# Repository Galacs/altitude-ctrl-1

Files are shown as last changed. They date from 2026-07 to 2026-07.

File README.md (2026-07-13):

# Altitude CTRL 1

## Pin definitions

```c
#define I2C_RST_PIN PC13
#define I2C_SDA PB11
#define I2C_SCL PB10

#define STEPPER_STEP PB6
#define STEPPER_DIR PB5
#define STEPPER_EN PB7
#define STEPPER_TX PA2
#define STEPPER_RX PA3

#define CAN_TX_PIN PB9
#define CAN_RX_PIN PB8
#define CAN_STAT_PIN PB12

#define PRESS_SNS_PIN PA7

#define LMS_PIN PB4
#define BTN_PIN PA11
#define BAU_PIN PA15

#define PUMP_PIN PB15
#define RL_1_PIN PB14
#define RL_2_PIN PB13

#define SPI_SCK_PIN PA5
#define SPI_MISO_PIN PA6
#define SPI_CS_PIN PA4
```

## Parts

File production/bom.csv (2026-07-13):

Designator | Footprint | Quantity | Value | LCSC Part #
C1, C12, C4, C49, C50, C51, C52 | 0805 | 7 | 10u | C440198
C10, C5, C6, C7, C8, C9 | 0805 | 6 | 22u | C45783
C11, C13, C16, C17, C18, C19, C22, C47 | 0402 | 8 | 0u1 | C307331
C14, C15 | 0603 | 2 | 20p | C1648
C2, C20, C21, C3, C53 | 0402 | 5 | 1u | C52923
C35 | 0402 | 1 | 4u7 | C23733
C36 | 0402 | 1 | 22n | C1532
D1, D2 | D_SMA | 2 | SMAJ12A | C19077531
D10 | 0805 | 1 | YELLOW | C2296
D12, D14, D16, D18, D5, D6, D7, D8, D9 | Diode_DFN1006 | 9 | H5VU10U | C22395519
D3, D4 | 0805 | 2 | GREEN | C2297
FB1 | 0805 | 1 | 600Ω@100M | C81034
J7 | PinHeader_1x02_P2.54mm_Vertical | 1 | Conn_01x02
R1, R10, R11, R41, R9 | 0402 | 5 | 10k | C25744
R12 | 0603 | 1 | 560 | C23204
R13, R4, R5, R6, R8 | 0402 | 5 | 5k1 | C25905
R14 | 0402 | 1 | 100 | C705627
R15 | 1206 | 1 | 120 | C17909
R2, R3, R36, R7 | 0402 | 4 | 1k | C11702
SW1, SW3, SW5 | SW_SPST_TS-1088-xR020 | 3 | SW_Push | C720477
U1 | SOT-89-3 | 1 | HT753-1 | C14289
U2 | SOIC-16_3.9x9.9mm_P1.27mm | 1 | ULN2003A | C7512
U3, U4 | Texas_RPW0010A_VQFN-HR-10_2x2mm_P0.5mm | 2 | LM73100 | C3210761
U5 | SOIC-8_3.9x4.9mm_P1.27mm | 1 | MAX6675 | C16030
U6 | LQFP-48_7x7mm_P0.5mm | 1 | STM32F103C8Tx | C8734
U7 | SOIC-8_3.9x4.9mm_P1.27mm | 1 | SN65HVD230 | C12084
U8 | VQFN-28-1EP_5x5mm_P0.5mm_EP3.7x3.7mm_ThermalVias | 1 | TMC2209-LA | C2150710
Y1 | Crystal_SMD_5032-2Pin_5.0x3.2mm | 1 | 8M | C115962

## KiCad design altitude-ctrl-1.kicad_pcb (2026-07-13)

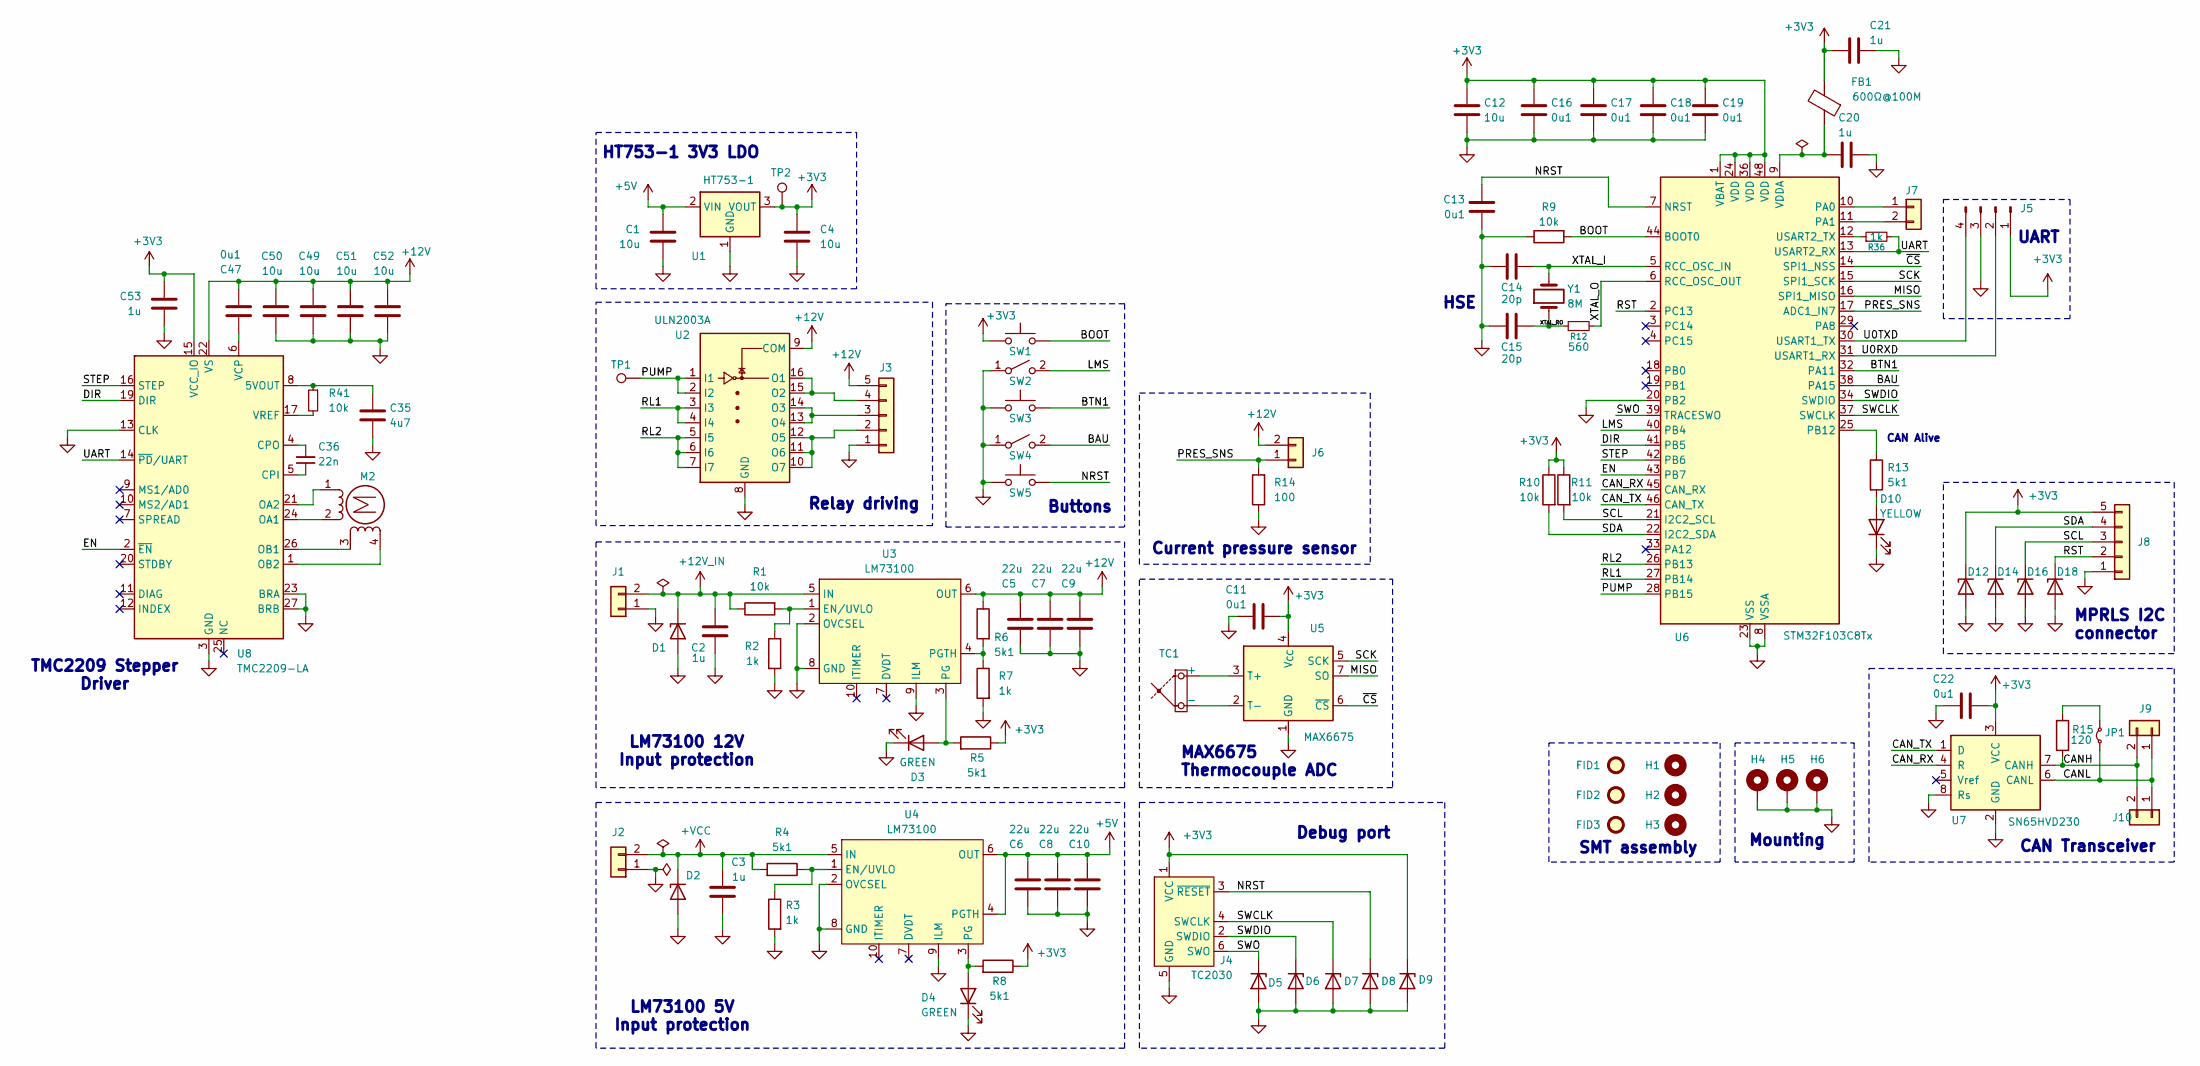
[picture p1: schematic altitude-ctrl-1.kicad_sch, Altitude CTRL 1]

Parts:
C1, C4, C12, C49, C50, C51, C52: 10u; C_0805_2012Metric; Manufacturer Part Number GRM21BR61H106KE43L; JLCPCB Part # C440198
C2, C3, C20, C21, C53: 1u; C_0402_1005Metric; Manufacturer Part Number CL05A105KA5NQNC; JLCPCB Part # C52923
C5, C6, C7, C8, C9, C10: 22u; C_0805_2012Metric; Manufacturer Part Number CL21A226MAQNNNE; JLCPCB Part # C45783
C11, C13, C16, C17, C18, C19, C22, C47: 0u1; C_0402_1005Metric; Manufacturer Part Number CL05B104KB54PNC; JLCPCB Part # C307331
C14, C15: 20p; C_0603_1608Metric; Manufacturer Part Number CL10C200JB8NNNC; JLCPCB Part # C1648
C35: 4u7; C_0402_1005Metric; Manufacturer Part Number CL05A475MP5NRNC; JLCPCB Part # C23733
C36: 22n; C_0402_1005Metric; Manufacturer Part Number 0402B223K500NT; JLCPCB Part # C1532
D1, D2: SMAJ12A; D_SMA; Manufacturer Part Number SMAJ12A; JLCPCB Part # C19077531
D3, D4: GREEN; LED_0805_2012Metric; Manufacturer Part Number KT-0805G; JLCPCB Part # C2297
D5, D6, D7, D8, D9, D12, D14, D16, D18: H5VU10U; Diode_DFN1006; Manufacturer Part Number H5VU10U; JLCPCB Part # C22395519
D10: YELLOW; LED_0805_2012Metric; Manufacturer Part Number KT-0805Y; JLCPCB Part # C2296
FB1: 600Ω@100M; L_0805_2012Metric; Manufacturer Part Number MPZ2012S601ATD25; JLCPCB Part # C81034
FID1, FID2, FID3: Fiducial; Fiducial_1mm_Mask2mm
H1, H2, H3: MountingHole; ToolingHole_1.152mm
H4, H5, H6: MountingHole_Pad; MountingHole_3.2mm_M3_Pad_Via
J1, J2, J6: Conn_01x02; TerminalBlock_Phoenix_MKDS-1,5-2-5.08_1x02_P5.08mm_Horizont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
J3, J8: Conn_01x05; TerminalBlock_Phoenix_MKDS-1,5-5-5.08_1x05_P5.08mm_Horizont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
J4: TC2030; Tag-Connect_TC2030-IDC-NL_2x03_P1.27mm_Vertical
J5: Conn_01x04_Pin; PinHeader_1x04_P2.54mm_Vertical
J7: Conn_01x02; PinHeader_1x02_P2.54mm_Vertical
J9, J10: Conn_01x02; JST_XH_B2B-XH-A_1x02_P2.50mm_Vertical
JP1: Jumper_2_Small_Bridged; PinHeader_1x02_P2.54mm_Vertical
M2: Stepper_Motor_bipolar; TerminalBlock_Phoenix_MKDS-1,5-4-5.08_1x04_P5.08mm_Horizont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
R1, R9, R10, R11, R41: 10k; R_0402_1005Metric; Manufacturer Part Number 0402WGF1002TCE; JLCPCB Part # C25744
R2, R3, R7, R36: 1k; R_0402_1005Metric; Manufacturer Part Number 0402WGF1001TCE; JLCPCB Part # C11702
R4, R5, R6, R8, R13: 5k1; R_0402_1005Metric; Manufacturer Part Number 0402WGF5101TCE; JLCPCB Part # C25905
R12: 560; R_0603_1608Metric; Manufacturer Part Number 0603WAF5600T5E; JLCPCB Part # C23204
R14: 100; R_0402_1005Metric; Manufacturer Part Number RT0402BRD07100RL; JLCPCB Part # C705627
R15: 120; R_1206_3216Metric; Manufacturer Part Number 1206W4F1200T5E; JLCPCB Part # C17909
SW1, SW3, SW5: SW_Push; SW_SPST_TS-1088-xR020; Manufacturer Part Number TS-1088-AR02016; JLCPCB Part # C720477
SW2, SW4: SW_SPST; TerminalBlock_Phoenix_MKDS-1,5-2-5.08_1x02_P5.08mm_Horizont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
TC1: Thermocouple_Block; TerminalBlock_Phoenix_MKDS-1,5-2-5.08_1x02_P5.08mm_Horizont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
TP1, TP2: TestPoint; TestPoint_Pad_D2.0mm
U1: HT753-1; SOT-89-3; Manufacturer Part Number HT7533-1; JLCPCB Part # C14289
U2: ULN2003A; SOIC-16_3.9x9.9mm_P1.27mm; Manufacturer Part Number ULN2003ADR; JLCPCB Part # C7512
U3, U4: LM73100; Texas_RPW0010A_VQFN-HR-10_2x2mm_P0.5mm; Manufacturer Part Number LM73100RPWR; JLCPCB Part # C3210761
U5: MAX6675; SOIC-8_3.9x4.9mm_P1.27mm; Manufacturer Part Number C16030; JLCPCB Part # C16030
U6: STM32F103C8Tx; LQFP-48_7x7mm_P0.5mm; Manufacturer Part Number STM32F103C8T6; JLCPCB Part # C8734
U7: SN65HVD230; SOIC-8_3.9x4.9mm_P1.27mm; Manufacturer Part Number SN65HVD230DR; JLCPCB Part # C12084
U8: TMC2209-LA; VQFN-28-1EP_5x5mm_P0.5mm_EP3.7x3.7mm_ThermalVias; Manufacturer Part Number TMC2209-LA-T; JLCPCB Part # C2150710
Y1: 8M; Crystal_SMD_5032-2Pin_5.0x3.2mm; Manufacturer Part Number X50328MSB2GI; JLCPCB Part # C115962

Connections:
+3V3: C4.1, C11.1, C12.1, C16.1, C17.1, C18.1, C19.1, C21.1, C22.1, C53.1, D9.1 (K), D12.1 (K), FB1.2, J4.1 (VCC), J5.1, J8.5, R5.1, R8.1, R10.1, R11.1, SW1.1, TP2.1 (1_1), U1.3 (VOUT), U5.4 (V_{CC}), U6.1 (VBAT), U6.24 (VDD), U6.36 (VDD), U6.48 (VDD), U7.3 (VCC), U8.15 (VCC_IO)
+5V: C1.1, C6.2, C8.2, C10.2, U1.2 (VIN), U4.4 (PGTH), U4.6 (OUT)
+12V: C5.2, C7.2, C9.2, C47.1, C49.1, C50.1, C51.1, C52.1, J3.5, J6.2, R6.1, U2.9 (COM), U3.6 (OUT), U8.22 (VS), U8.28 (VS)
+12V_IN: C2.2, D1.1 (K), J1.2, R1.1, U3.5 (IN)
+VCC: C3.2, D2.1 (K), J2.2, R4.2, U4.5 (IN)
/BAU: SW4.2 (B), U6.38 (PA15)
/BOOT: R9.2, SW1.2, U6.44 (BOOT0)
/BTN1: SW3.2, U6.32 (PA11)
/CANH: J9.2, J10.2, R15.1, U7.7 (CANH)
/CANL: J9.1, J10.1, JP1.1 (A), U7.6 (CANL)
/CAN_RX: U6.45 (CAN_RX), U7.4 (R)
/CAN_TX: U6.46 (CAN_TX), U7.1 (D)
/DIR: U6.41 (PB5), U8.19 (DIR)
/EN: U6.43 (PB7), U8.2 (~EN)
/LMS: SW2.2 (B), U6.40 (PB4)
/MISO: U5.7 (SO), U6.16 (SPI1_MISO)
/NRST: C13.1, D8.1 (K), J4.3 (~RESET), SW5.2, U6.7 (NRST)
/PRES_SNS: J6.1, R14.2, U6.17 (ADC1_IN7)
/PUMP: TP1.1 (1_1), U2.1 (I1), U2.2 (I2), U6.28 (PB15)
/RL1: U2.3 (I3), U2.4 (I4), U6.27 (PB14)
/RL2: U2.5 (I5), U2.6 (I6), U2.7 (I7), U6.26 (PB13)
/RST: D18.1 (K), J8.2, U6.2 (PC13)
/SCK: U5.5 (SCK), U6.15 (SPI1_SCK)
/SCL: D16.1 (K), J8.3, R11.2, U6.21 (I2C2_SCL)
/SDA: D14.1 (K), J8.4, R10.2, U6.22 (I2C2_SDA)
/STEP: U6.42 (PB6), U8.16 (STEP)
/SWCLK: D7.1 (K), J4.4 (SWCLK), U6.37 (SWCLK)
/SWDIO: D6.1 (K), J4.2 (SWDIO), U6.34 (SWDIO)
/SWO: D5.1 (K), J4.6 (SWO), U6.39 (TRACESWO)
/U0RXD: J5.2, U6.31 (USART1_RX)
/U0TXD: J5.4, U6.30 (USART1_TX)
/UART: R36.2, U6.13 (USART2_RX), U8.14 (~PD/UART)
/XTAL_I: C14.1, U6.5 (RCC_OSC_IN), Y1.2
/XTAL_O: R12.2, U6.6 (RCC_OSC_OUT)
/XTAL_RO: C15.1, R12.1, Y1.1
/~CS: U5.6 (~CS), U6.14 (SPI1_NSS)
GND: C1.2, C2.1, C3.1, C4.2, C5.1, C6.1, C7.1, C8.1, C9.1, C10.1, C11.2, C12.2, C13.2, C14.2, C15.2, C16.2, C17.2, C18.2, C19.2, C20.2, C21.2, C22.2, C35.2, C49.2, C50.2, C51.2, C52.2, C53.2, D1.2 (A), D2.2 (A), D3.1 (K), D4.1 (K), D5.2 (A), D6.2 (A), D7.2 (A), D8.2 (A), D9.2 (A), D10.1 (K), D12.2 (A), D14.2 (A), D16.2 (A), D18.2 (A), H4.1 (1_1), H5.1 (1_1), H6.1 (1_1), J1.1, J2.1, J3.1, J4.5 (GND), J5.3, J8.1, R2.2, R3.2, R7.2, R9.1, R14.1, SW2.1 (A), SW3.1, SW4.1 (A), SW5.1, U1.1 (GND), U2.8 (GND), U3.2 (OVCSEL), U3.8 (GND), U3.9 (ILM), U4.2 (OVCSEL), U4.8 (GND), U4.9 (ILM), U5.1 (GND), U6.8 (VSSA), U6.20 (PB2), U6.23 (VSS), U6.35 (VSS), U6.47 (VSS), U7.2 (GND), U7.8 (Rs), U8.3 (GND), U8.13 (CLK), U8.18 (GND), U8.23 (BRA), U8.27 (BRB), U8.29 (GND)
unnamed: D3.2 (A), R5.2, U3.3 (PG)
unnamed: D4.2 (A), R8.2, U4.3 (PG)
unnamed: D10.2 (A), R13.2
unnamed: J3.2, U2.10 (O7), U2.11 (O6), U2.12 (O5)
unnamed: J3.3, U2.13 (O4), U2.14 (O3)
unnamed: J3.4, U2.15 (O2), U2.16 (O1)
unnamed: J7.1, U6.10 (PA0)
unnamed: J7.2, U6.11 (PA1)
unnamed: JP1.2 (B), R15.2
unnamed: M2.1 (-_1), U8.21 (OA2)
unnamed: TC1.1 (+), U5.3 (T+)
unnamed: TC1.2 (-), U5.2 (T-)
unnamed: R1.2, R2.1, U3.1 (EN/UVLO)
unnamed: R6.2, R7.1, U3.4 (PGTH)
unnamed: R3.1, R4.1, U4.1 (EN/UVLO)
unnamed: R36.1, U6.12 (USART2_TX)
unnamed: R13.1, U6.25 (PB12)
unnamed: C20.1, FB1.1, U6.9 (VDDA)
unnamed: C35.1, R41.1, U8.8 (5VOUT)
unnamed: C36.1, U8.5 (CPI)
unnamed: C36.2, U8.4 (CPO)
unnamed: M2.2, U8.24 (OA1)
unnamed: M2.3, U8.26 (OB1)
unnamed: M2.4, U8.1 (OB2)
unnamed: C47.2, U8.6 (VCP)
unnamed: R41.2, U8.17 (VREF)

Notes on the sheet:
MAX6675 Thermocouple ADC
LM73100 5V Input protection
Debug port
Mounting
HT753-1 3V3 LDO
LM73100 12V Input protection
SMT assembly
MPRLS I2C connector
HSE
Relay driving
CAN Alive
Buttons
TMC2209 Stepper Driver
UART
Current pressure sensor
CAN Transceiver

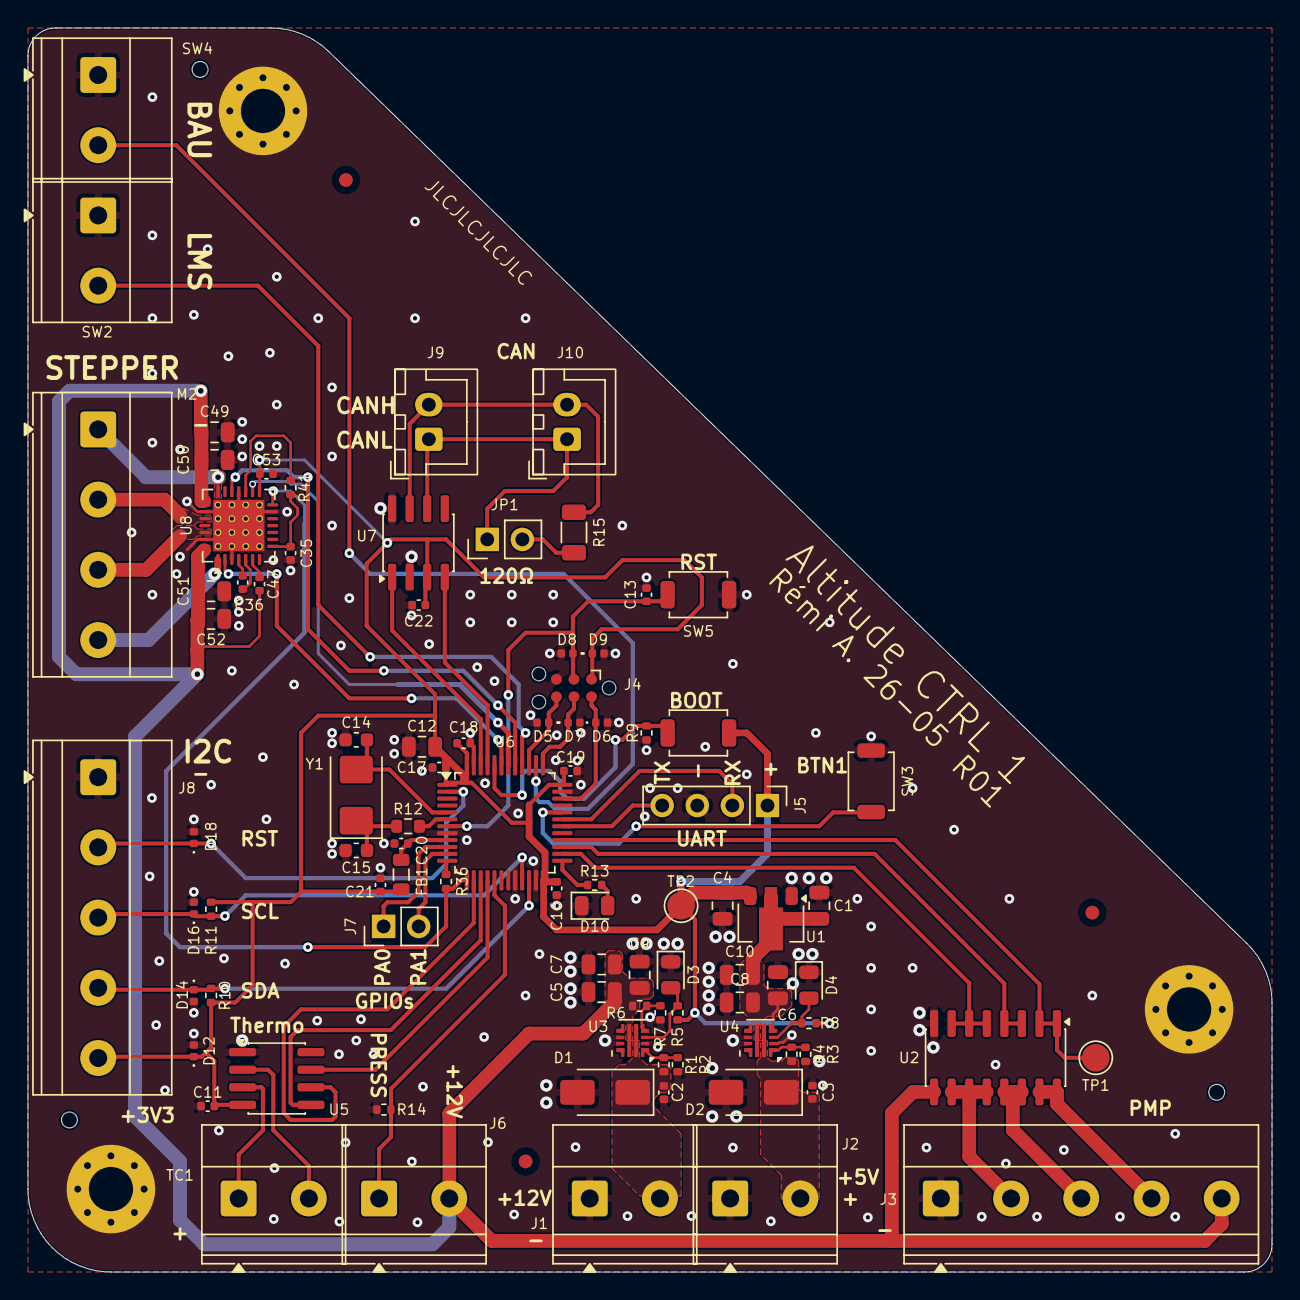
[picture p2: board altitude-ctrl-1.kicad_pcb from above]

Board: 2 copper layers, 90.0 x 90.0 mm, 100 parts (0 on the bottom side), 63 nets.

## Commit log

2026-07-08 schem: import stm32f4
    [altitude-ctrl-1.kicad_pcb, altitude-ctrl-1.kicad_sch]
2026-07-08 schem: import ldo, mnt holes, ldo, btns and fiducials
    [altitude-ctrl-1.kicad_sch]
2026-07-08 schem: import tag connect swd
    [altitude-ctrl-1.kicad_sch]
2026-07-08 schem: import can transceiver
    [altitude-ctrl-1.kicad_sch]
2026-07-08 schem: import LM73100 Ideal diode
    [altitude-ctrl-1.kicad_sch]
2026-07-08 schem: add LM73100 Ideal diode ov protection
    [altitude-ctrl-1.kicad_sch]
2026-07-08 schem: add LM73100 +12V input protection
    [altitude-ctrl-1.kicad_sch]
2026-07-08 schem: add input tvs
    [altitude-ctrl-1.kicad_sch]
2026-07-08 schem: add power input conns
    [altitude-ctrl-1.kicad_sch]
2026-07-08 schem: add MAX6675 Thermocouple ADC
    [altitude-ctrl-1.kicad_sch]
2026-07-08 schem: add Current pressure sensor
    [altitude-ctrl-1.kicad_sch]
2026-07-08 schem: add BAU symbol
    [altitude-ctrl-1.kicad_sch]
2026-07-08 schem: add relay driving circuit
    [altitude-ctrl-1.kicad_sch]
2026-07-08 schem: add MPRLS I2C connector
    [altitude-ctrl-1.kicad_sch]
2026-07-08 schem: add LMS symbol
    [altitude-ctrl-1.kicad_sch]
2026-07-08 schem: add stepper interface
    [altitude-ctrl-1.kicad_sch]
2026-07-08 schem: reorganize
    [altitude-ctrl-1.kicad_sch]
2026-07-08 schem: connect gpios to mcu
    [altitude-ctrl-1.kicad_sch]
2026-07-08 schem: fix LM73100s ov resistors
    [altitude-ctrl-1.kicad_sch]
2026-07-08 schem: fix 12v LM73100 pgth voltage
    [altitude-ctrl-1.kicad_sch]
2026-07-08 schem: add no connects
    [altitude-ctrl-1.kicad_sch]
2026-07-08 schem: add test points
    [altitude-ctrl-1.kicad_sch]
2026-07-08 schem: run and fix ERC
    [altitude-ctrl-1.kicad_sch]
2026-07-08 schem: add missing footprints
    [altitude-ctrl-1.kicad_sch]
2026-07-08 schem: update exlude from BOM
    [altitude-ctrl-1.kicad_sch]
2026-07-08 schem: add title
    [altitude-ctrl-1.kicad_sch]
2026-07-08 schem: renumber
    [altitude-ctrl-1.kicad_sch]
2026-07-08 pcb: import jlc 2 layer stackup
    [altitude-ctrl-1.kicad_pcb]
2026-07-08 pcb: import components from schem
    [altitude-ctrl-1.kicad_pcb]
2026-07-08 pcb: add initial sectioning
    [altitude-ctrl-1.kicad_pcb]
2026-07-08 pcb: add +12v input protection layout
    [altitude-ctrl-1.kicad_pcb]
2026-07-08 pcb: add +5v input protection layout
    [altitude-ctrl-1.kicad_pcb]
2026-07-08 pcb: add thermocouple layout
    [altitude-ctrl-1.kicad_pcb]
2026-07-08 pcb: add can layout
    [altitude-ctrl-1.kicad_pcb]
2026-07-08 pcb: add relay layout
    [altitude-ctrl-1.kicad_pcb]
2026-07-08 pcb: add board outline and mnt holes
    [altitude-ctrl-1.kicad_pcb]
2026-07-08 pcb: edit board outline
    [altitude-ctrl-1.kicad_pcb, altitude-ctrl-1.kicad_sch]
2026-07-08 pcb: initial placement
    [altitude-ctrl-1.kicad_pcb]
2026-07-08 pcb: place fiducials and mounting holes
    [altitude-ctrl-1.kicad_pcb]
2026-07-08 pcb: reorganize programmable gpios
    [altitude-ctrl-1.kicad_pcb, altitude-ctrl-1.kicad_sch]
2026-07-08 schem/pcb: add spare gpios
    [altitude-ctrl-1.kicad_pcb, altitude-ctrl-1.kicad_sch]
2026-07-08 pcb: finish placement
    [altitude-ctrl-1.kicad_pcb]
2026-07-08 pcb: add gnd planes
    [altitude-ctrl-1.kicad_pcb]
2026-07-08 pcb: add gnd vias
    [altitude-ctrl-1.kicad_pcb]
2026-07-08 pcb: add drill/place origin
    [altitude-ctrl-1.kicad_pcb]
2026-07-08 pcb: add xtal routing
    [altitude-ctrl-1.kicad_pcb]
2026-07-08 pcb: add swd routing
    [altitude-ctrl-1.kicad_pcb]
2026-07-08 pcb: add can routing
    [altitude-ctrl-1.kicad_pcb]
2026-07-08 pcb: add uart routing
    [altitude-ctrl-1.kicad_pcb]
2026-07-08 pcb: add spi/thermocouple routing
    [altitude-ctrl-1.kicad_pcb]
2026-07-08 pcb: add +12v efuse routing
    [altitude-ctrl-1.kicad_pcb]
2026-07-08 pcb: add +5V input protection routing
    [altitude-ctrl-1.kicad_pcb]
2026-07-08 pcb: add i2c routing
    [altitude-ctrl-1.kicad_pcb]
2026-07-08 pcb: add relay driver routing
    [altitude-ctrl-1.kicad_pcb]
2026-07-08 pcb: add can status led routing
    [altitude-ctrl-1.kicad_pcb]
2026-07-08 pcb: add gpio routing
    [altitude-ctrl-1.kicad_pcb]
2026-07-08 pcb: add steper, lms & bau routing
    [altitude-ctrl-1.kicad_pcb]
2026-07-08 pcb: add misc power routing
    [altitude-ctrl-1.kicad_pcb]
2026-07-08 pcb: add boot routing
    [altitude-ctrl-1.kicad_pcb]
2026-07-08 pcb: add +3V3 pwr routing
    [altitude-ctrl-1.kicad_pcb]
2026-07-08 pcb: add missing routing
    [altitude-ctrl-1.kicad_pcb]
2026-07-08 pcb: add stitching vias
    [altitude-ctrl-1.kicad_pcb]
2026-07-08 pcb(silk): clean up reference
    [altitude-ctrl-1.kicad_pcb]
2026-07-08 pcb(silk): add user txt
    [altitude-ctrl-1.kicad_pcb, altitude-ctrl-1.kicad_sch]
2026-07-09 schem: replace stepper interface with tmc2209 driver
    [altitude-ctrl-1.kicad_sch]
2026-07-09 pcb: add tmc2209 layout & routing
    [altitude-ctrl-1.kicad_pcb, altitude-ctrl-1.kicad_sch]
2026-07-09 pcb(silk): add logo and png
    [altitude-ctrl-1.kicad_pcb]
2026-07-09 pcb: add title
    [altitude-ctrl-1.kicad_pcb]
2026-07-13 regenerate production files
    [altitude-ctrl-1.kicad_pcb, bom.csv, designators.csv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]
2026-07-13 docs: add pin definitions
